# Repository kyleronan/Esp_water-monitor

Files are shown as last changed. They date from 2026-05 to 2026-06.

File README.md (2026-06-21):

# Water Monitor

A DIY Home Assistant addon and ESP32-based smart water shut-off valve.
Tracks pressure and flow, learns your home's normal usage, runs scheduled leak
tests, and lets you cut off water to the house from anywhere — without
subscriptions, cloud polling, or trips to the crawl space.

## Background

This started as a hobby project. I wasn't happy with the commercial options
(Moen Flo, StreamLabs Control) — they polled the internet for things that
should work locally, and put basic features behind subscriptions. I also got
tired of crawling under the house every winter to shut off water to the
irrigation, and wanted something I could trigger from an app or a wall switch.

So I built one. It's not as pretty or compact as the off-the-shelf products,
but it has most of the same basic features and runs entirely on my own LAN.

A few design choices worth knowing about up front:

- **Manual override matters.** From day one this had to work with physical
  switches and indicator lights, not just the web UI. If the network is down,
  if I'm not home, if Home Assistant is misbehaving — anyone in the house
  can still open or close the valve.
- **Two circuits.** Main (whole house) plus irrigation. The irrigation valve
  is the one I shut off for winter; having it on a separate circuit makes
  the seasonal routine a one-tap operation.
- **Overbuilt by choice.** Three-piece stainless steel ball valves (serviceable,
  lead-free, more trustworthy than the brass valves on AliExpress), motorised
  actuators with a manual override for power outages, separate pressure
  transducers and flow meters per circuit. You could absolutely build this
  with cheaper parts — most of the firmware doesn't care.
- **Cost-conscious sourcing.** Most components came from AliExpress because the
  same parts from local plumbing/HVAC suppliers were 10× the price. Links to
  what I actually used will go in `docs/` once the hardware build guide is
  written.
- **PCB caveat.** This was my first SMD design. The current revision works,
  but I have a small pile of boards on my shelf that don't. The board is
  optimised for *my* situation, not for manufacturing efficiency or BOM cost.

## On the code

I should be upfront about how this got built. I'm an amateur C coder at best,
and my prior web experience tops out at script-kiddie HTML and Java tinkering.
The firmware was within reach — I had a basically functional firmware and the
valve sitting in the basement "ready" for testing since August 2025 — but the
prospect of writing the Home Assistant addon, with its FastAPI backend, async
WebSockets, Jinja2 templates, SQLite migrations, and clustering algorithms, kept
stalling out against my ADHD. It sat on the shelf for a long time.

So I leaned on AI heavily and did a fair amount of vibe coding to get the
addon to a state where it's actually usable. Originally I figured this whole
project was just for me, but along the way I realised I should at least flesh
it out enough that someone else could build on the idea if they wanted to.
That's why the addon code is more polished than I'd ever have produced on my
own — and also why it might have rough edges only an experienced developer
would have caught.

If you find bugs or design choices that look weird, that's probably why. PRs
welcome.

## TL;DR

I made a thing. It mostly works. If you want to copy it or improve on it,
that's great. I'm probably not going to build another one for myself.

## What it does

- **Real-time monitoring** — pressure and flow on the main and irrigation
  circuits, displayed in the units you choose (L/min · gal/min · ft³/min ·
  m³/min, and PSI · bar · kPa)
- **Learned baseline** — 14-day calibration period during which the addon
  watches your normal usage patterns. When training ends, the Fixtures
  page lists the clusters that were detected; you confirm or remove them,
  then activate the circuit to start anomaly detection (or auto-activates
  after 7 days of no review).
- **Scheduled micro leak tests** — closes each valve in turn at the
  statistically quietest hour of the day, monitors pressure decay, and notifies
  on failure
- **Fixture identification** — clusters water events by their pressure and
  flow signatures to identify individual fixtures (toilets, showers, taps,
  appliances). Live in v0.2.0; naming UI complete; merge-clusters UI and
  ESP-side waveform enrichment added in v0.2.1.
- **Event detail modal** — every event in the History list opens an
  inspector with trigger type, peak flow, propagation delay, anomaly score
  and (with firmware v3.7+) an embedded waveform chart. Events can be
  re-assigned to a fixture or ignored from this view.
- **Degraded-supply guard** (v0.2.2) — detects when the municipal supply
  is pulsing (paddlewheel flow sensors produce garbage under those
  conditions). Affected events are flagged, given an envelope-smoothed
  volume so daily totals stay sensible, and excluded from clustering. The
  Dashboard shows a banner and the History page has a filter.
- **Per-circuit valve type** (v0.2.2) — Setup and Settings let you mark
  each circuit as 2-port (standard) or 3-port (drain-capable for
  winterization). 3-port circuits automatically skip the micro leak test
  (the drain port reads as a constant leak); the schedule is preserved
  if you ever switch back.
- **Runtime flow-meter calibration** (v0.2.2) — pulses-per-litre is a
  per-circuit Home Assistant number entity (NVS-backed, survives OTA), so
  any flow meter works without a firmware edit. A guided **calibration
  helper** (Settings → Flow Meter → Calibrate) measures the true
  pulses-per-litre from a bucket test or a whole-house municipal-meter
  reading — showing each run, their average and range, with an editable,
  safety-gated value before you apply.
- **Anomaly detection** (v0.2.2, Phase 2.3) — flags events that deviate from
  the learned baseline (volume percentiles + per-fixture envelopes) and can
  notify or auto-shut-off, guarded so a thin/young baseline degrades to
  notify-only.
- **Away mode** — pauses learning while unoccupied, automatically toggled
  from your existing HA presence entities
- **Mobile push notifications** for all alerts via HA's `notify.mobile_app_*`
  services, with per-target backoff after repeated failures so a broken
  mobile_app integration doesn't spam the logs.
- **Full backup and restore** — three-tier backup (Quick Restore JSON, History
  Archive SQLite, Full ZIP) with restore-from-backup in the setup wizard
- **Auto dark mode** — the UI follows your OS / browser appearance
  preference automatically. No toggle, no setup.

## Repository structure

This is a Home Assistant addon repository. It also contains the firmware,
documentation, and (eventually) a companion native HA integration.

```
.
├── repository.yaml      # HA addon repository metadata
├── water_monitor/       # The addon itself (HA expects this at the root)
│   ├── config.yaml
│   ├── Dockerfile
│   ├── icon.png         # Addon icon (128 × 128) — shown on HA addon card
│   ├── logo.png         # Addon logo (250 × 100) — shown on HA store detail page
│   └── app/
├── firmware/            # ESPHome firmware for the ESP32-S3-WROOM-1
├── integration/         # Native HA integration (planned for v0.4)
└── docs/                # Hardware build notes, pinouts, parts list
```

## Installation

### Addon

1. In Home Assistant: **Settings → Add-ons → Add-on Store**
2. Open the three-dot menu (top right) → **Repositories**
3. Paste this repository's URL:
   ```
   https://github.com/kyleronan/Esp_water-monitor
   ```
4. Click **Add**, then close the dialog
5. The **Water Monitor** addon will appear in the store — click it and **Install**
6. Open the addon's web UI and follow the setup wizard

Updates are delivered automatically — when a new version is pushed to this
repository, the HA addon store will offer the update.

### Hardware

You'll need the ESP32-S3-WROOM-1 board (custom PCB), motorised ball valves
with end-stop signalling, pressure transducers, and pulse-output flow meters.

> **If your home has a pressure boosting pump or well pump system**, install
> the addon's flow and pressure sensors *downstream* of the pump (between the
> pump output and the house plumbing). Sensors placed upstream see pump cycling
> artifacts that mask individual fixture pressure signatures, making the
> fixture identification feature in v0.2.x unreliable. Downstream placement is
> also what every reasonable installation diagram recommends regardless of
> monitoring.

PCB design files (KiCad + Gerbers), bill of materials, build guide, and bring-up checklist are in [`docs/hardware/`](docs/hardware/).

### Firmware

1. Copy `firmware/secrets.yaml.example` to `firmware/secrets.yaml` and fill
   in the five values (API encryption key, OTA password, fallback-AP
   password, web UI username + password). See
   [`firmware/README.md`](firmware/README.md) for the key-generation
   snippet and the security model.
2. Flash `firmware/esp-water-shut-off-3_12.yaml` (v3.12.0) to your
   ESP32-S3-WROOM-1 using ESPHome.
3. Make sure the device is added to Home Assistant before installing the
   addon.
4. The setup wizard will discover the device automatically.

Before tagging a firmware release, run
`python scripts/check_firmware_release.py` — it parses the YAML and
fails if any credential is missing or if `dashboard_import` still
points at a mutable branch ref.

## Project status

| Phase | Scope | Status |
|---|---|---|
| **0.1.x** | Core monitoring, leak detection, calibration, display units | Shipped |
| **0.2.0** | Fixture identification — clustering engine live, naming UI complete | Shipped |
| **0.2.1** | ESP-side waveform capture & feature enrichment, event detail modal, merge-clusters UI, Basic/Advanced settings split, auto dark mode, hardware docs (PCB v1.2a) | Shipped |
| **0.2.2** | Runtime per-circuit flow-meter PPL + guided flow-calibration helper (bucket / municipal), Phase 2.3 anomaly detection, degraded-supply guard, per-circuit valve type (2-port / 3-port), per-session CSRF refactor, autocorrelation correctness fix, firmware release-gate script, migration transaction safety, async/blocking SQLite audit, live-capture reliability fixes (importer catch-up checkpoint + stuck no-flow phantom close) | Shipped |
| **0.3.x** | Per-circuit pressure-sensor calibration, esp_idf framework migration with proper task watchdog | Planned |
| **0.4.x** | Native Home Assistant integration (alongside the addon, eventually replacing the WebSocket bridge for users who prefer pip-installable components) | Planned |

See `CHANGELOG.md` for detailed release notes, and
[`docs/TODO.md`](docs/TODO.md) for the running list of manual follow-ups
(real-sample capture for the degraded-supply detector, per-circuit
pressure calibration, etc).

## License

MIT — see `LICENSE` file. Use it, modify it, sell it, build a better one,
whatever you like. Attribution is appreciated but not required.

## Contributing

This repository is in active development; the API and database schema may
change between minor versions. If you build one and find bugs or have ideas,
issues and PRs are welcome — though responses may be slow given this is a
side project.

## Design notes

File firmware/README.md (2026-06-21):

# Firmware — ESP Water Monitor

ESPHome firmware for the ESP32 water shut-off controller. 

## First-time setup

Before compiling you must create a `secrets.yaml` file in this directory:

```bash
cp firmware/secrets.yaml.example firmware/secrets.yaml
```

Then edit `firmware/secrets.yaml` and fill in all values. ESPHome will refuse to
compile if any `!secret` key is missing.

**Do not commit `secrets.yaml`** — it is listed in `.gitignore`.

### Generating an API encryption key

The `api_encryption_key` must be a base64-encoded 32-byte random value:

```bash
python3 -c "import base64, os; print(base64.b64encode(os.urandom(32)).decode())"
```

Paste the output into `secrets.yaml` as the value for `api_encryption_key`.

## Security notes

| Feature | Config |
|---|---|
| ESPHome API | Encrypted — key in `secrets.yaml` |
| OTA updates | Password-protected — set in `secrets.yaml` |
| Fallback hotspot | Password-protected — set in `secrets.yaml` |
| Built-in web UI | Basic auth — credentials in `secrets.yaml` |
| Bluetooth provisioning | `authorizer: none` — any nearby device can provision via Improv. Disable `esp32_improv` in the YAML if this is a concern. |

## Per-circuit pressure calibration

Both pressure transducers default to a shared factory-typical linear
fit. After bench measurement, override the per-circuit calibration via
the `substitutions:` block at the top of
`esp-water-shut-off-3_10.yaml` — eight values
(`pressure_cal_main_zero_raw / _psi`, `pressure_cal_main_max_raw /
_psi`, plus the irrigation counterparts). See
[`docs/hardware/bring-up-checklist.md`](../docs/hardware/bring-up-checklist.md)
for the two-point measurement procedure.

The defaults work for un-calibrated installs (existing flashes keep
their behaviour unchanged), but per-circuit calibration removes
transducer-to-transducer bias and makes the micro leak test more
sensitive.

## Releasing

Before tagging a firmware release, run the release-check script:

```bash
python scripts/check_firmware_release.py
```

It fails (non-zero exit) when any of these are missing or wrong in
`firmware/esp-water-shut-off-3_10.yaml`:

- `api.encryption.key`
- `ota[*].password`
- `wifi.ap.password`
- `web_server.auth.username` / `web_server.auth.password`
- `dashboard_import.package_import_url` not pinned to an immutable tag
  (`@v3.10.0`, etc.) or commit SHA — `@main` is rejected

When bumping the firmware version, update `dashboard_import.package_import_url`
to the new tag at the same time as the version field. The check script
parses the YAML, so commented-out example lines don't fool it.

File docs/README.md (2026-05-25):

# Hardware Documentation

See [docs/hardware/README.md](hardware/README.md) for the hardware build guide,
bill of materials, and bring-up checklist.

See [firmware/esp-water-shut-off-3_10.yaml](../firmware/esp-water-shut-off-3_10.yaml)
for the current ESPHome configuration.

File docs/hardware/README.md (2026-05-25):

# Hardware Documentation

This folder documents the ESP32 Water Valve Controller hardware build.

Use the board labels from the PCB and KiCad files throughout the hardware docs:

- Valve 1
- Valve 2

Software may allow custom names later, but the hardware build guide uses the physical board labels.

## Main documents

- `bom.md` - simplified builder-facing BOM
- `pinouts.md` - board connector pinouts
- `breakaway-front-panel-controls.md` - optional manual/auto front-panel control board
- `bring-up-checklist.md` - first power-up and test checklist

## Hardware Build Guide

This is a high-level build guide for the ESP32 Water Valve Controller hardware.

### Build order

1. Inspect the bare PCB.
2. Assemble the PCB.
3. Inspect solder joints and orientation-sensitive parts.
4. Separate the breakaway front-panel control section if it will be used.
5. Mount the main PCB in the enclosure.
6. Mount the breakaway control section and panel LEDs on the enclosure front panel.
7. Wire the 12 V DIN rail power supply and DIN terminal blocks.
8. Wire Valve 1 and Valve 2.
9. Wire the flow and pressure sensors.
10. Power up without plumbing pressure and run the bring-up checklist.
11. Test valve open/close behavior.
12. Test sensor readings.
13. Perform plumbing tests and calibration.

## Build photos

These photos document the prototype, assembly, enclosure wiring, plumbing test, pressure calibration, front panel, and breakaway switch wiring.

### Photo index

| Photo | Description |
| --- | --- |
| [Early prototyping](images/early-prototyping.jpg) | Early hardware prototyping before the final enclosure layout. |
| [Soldering complete](images/soldering-complete.jpg) | Assembled PCB after soldering. |
| [First enclosure wiring and testing](images/first-enclosure-wiring-and-testing.jpg) | Initial wiring inside the enclosure during testing. |
| [First plumbing test](images/first-plumbing-test-hose-floor-drain.jpg) | Initial plumbing test using a hose and floor drain. |
| [Pressure sensor calibration](images/pressure-sensor-calibration-analog-gauge.jpg) | Pressure sensor calibration using an analog pressure gauge. |
| [Inside of enclosure](images/inside-enclosure.jpg) | Internal enclosure layout with mounted electronics and wiring. |
| [Breakaway switch board wiring](images/breakaway-switch-board-bypass-wiring-enclosure-door.jpg) | Breakaway switch/control board bypass wiring mounted on the enclosure door. |
| [Outside of enclosure with LEDs](images/outside-enclosure-leds-wip.jpg) | Front of the enclosure showing panel LEDs. Work in progress; final labels still needed. |
| [ESP32-S3 WROOM-1 pinout](images/esp32s3_wroom1_pinout.png) | Pin reference diagram for the ESP32-S3 WROOM-1 module used in this build. |

### Gallery

#### Early prototyping

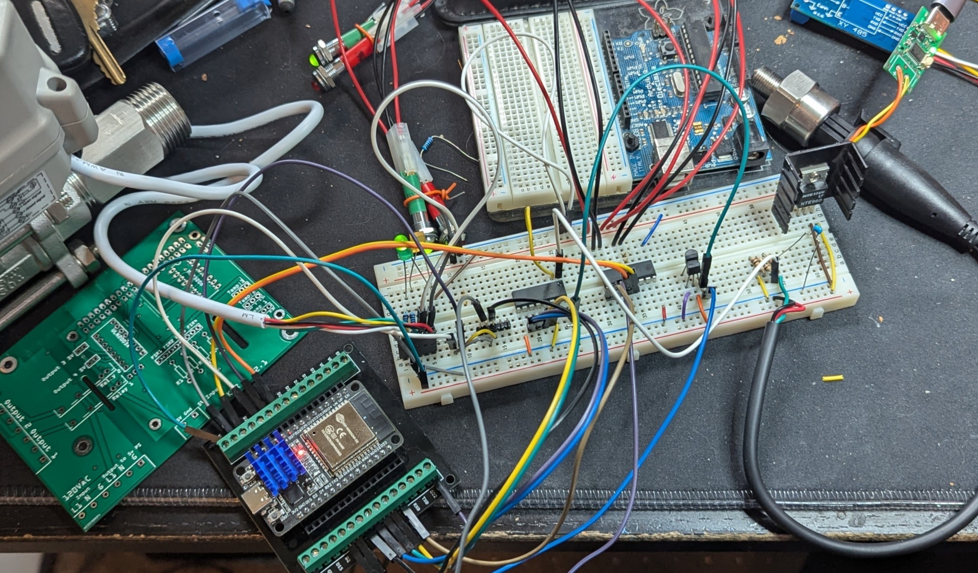
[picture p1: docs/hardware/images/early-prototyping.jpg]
Early prototyping


Early hardware prototyping before the final enclosure layout.

#### Soldering complete

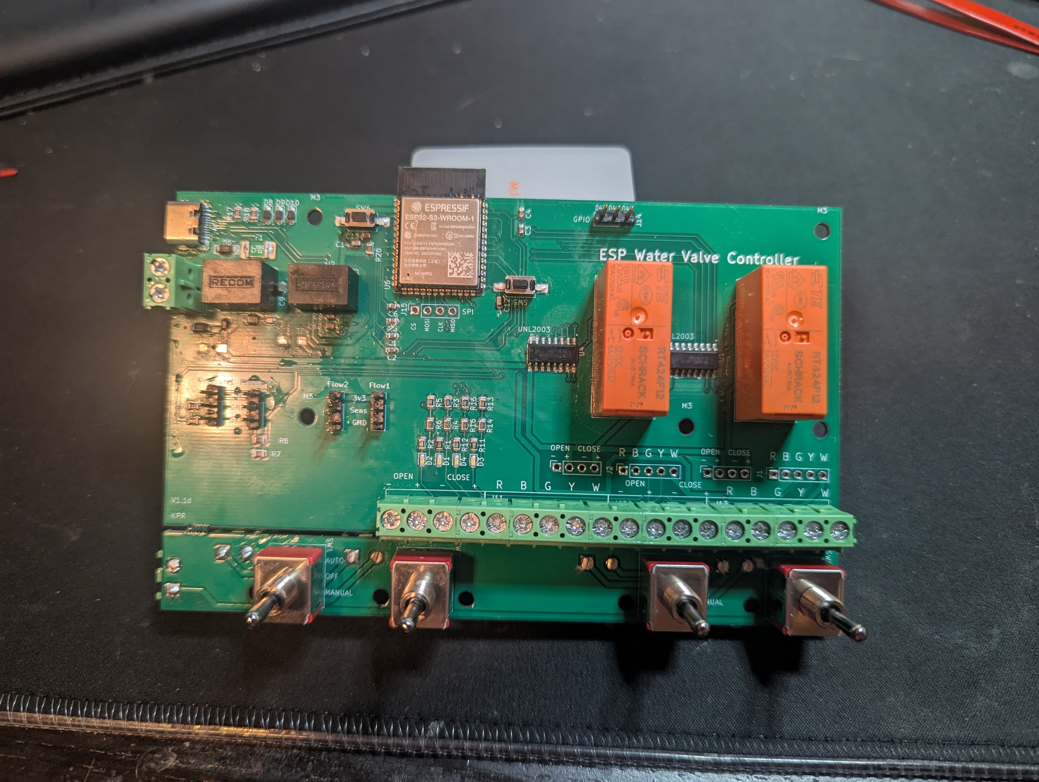
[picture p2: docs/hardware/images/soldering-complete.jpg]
Soldering complete


Assembled PCB after soldering.

#### First enclosure wiring and testing

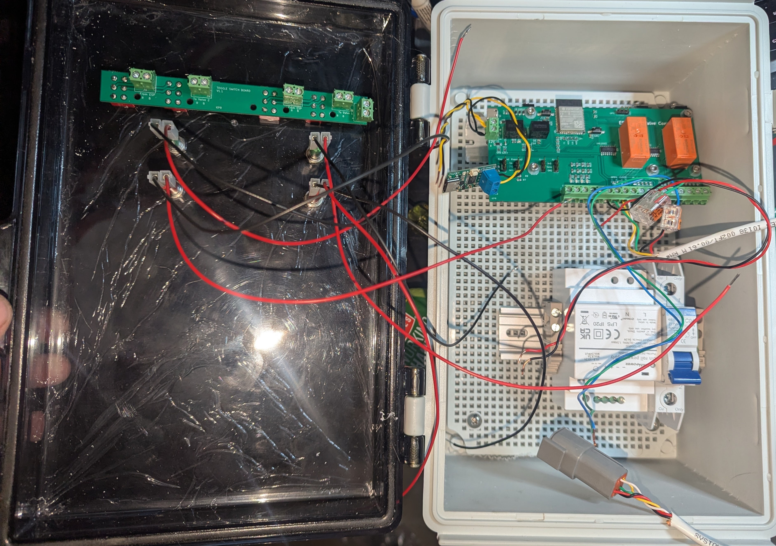
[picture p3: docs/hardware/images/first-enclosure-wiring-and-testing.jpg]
First enclosure wiring and testing


Initial wiring inside the enclosure during testing.

#### First plumbing test

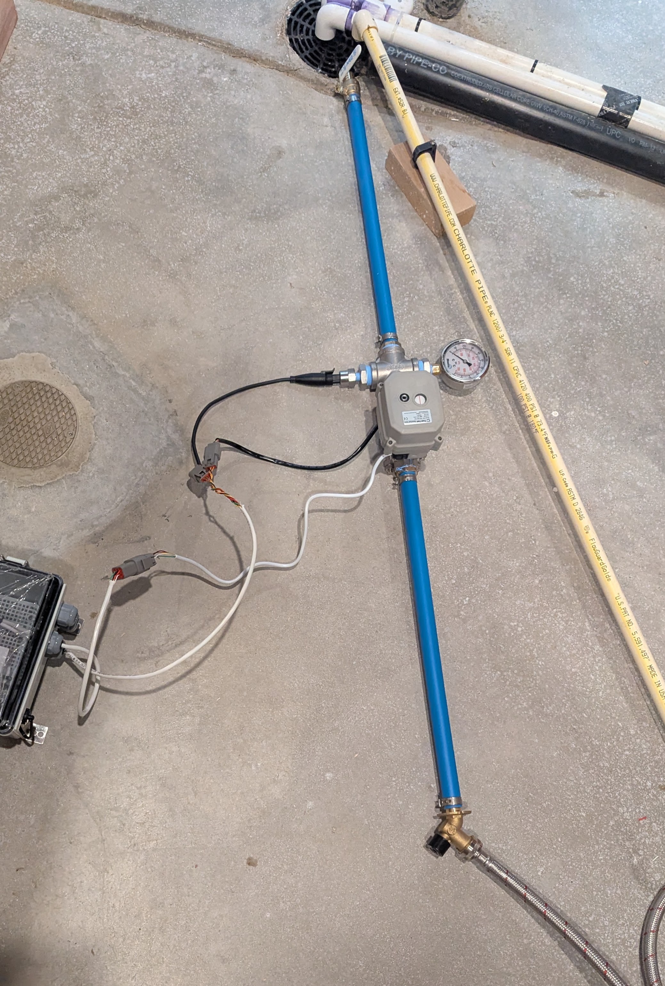
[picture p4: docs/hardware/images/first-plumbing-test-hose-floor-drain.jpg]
First plumbing test


Initial plumbing test using a hose and floor drain.
#### Pressure sensor calibration

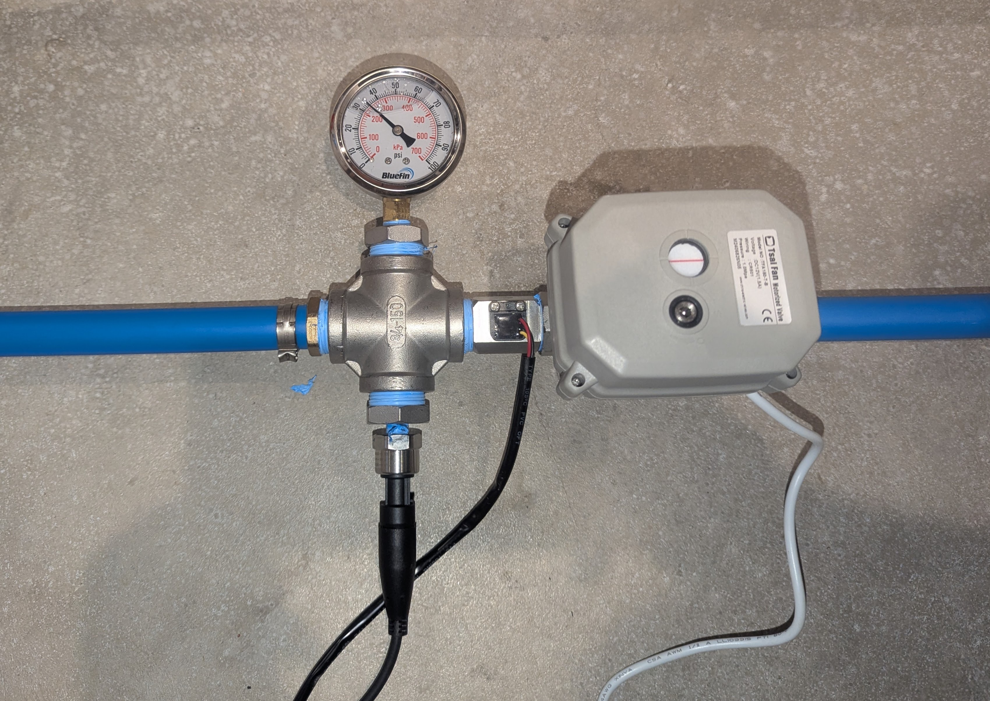
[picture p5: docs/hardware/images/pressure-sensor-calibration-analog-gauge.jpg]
Pressure sensor calibration


Pressure sensor calibration using an analog pressure gauge.

#### Inside of enclosure

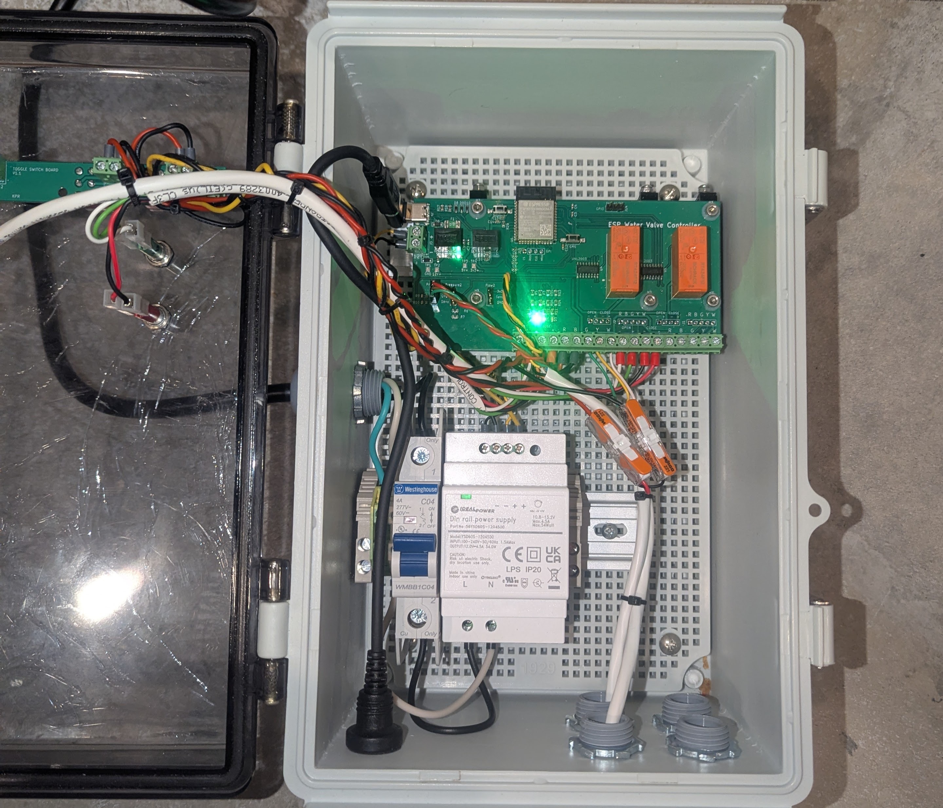
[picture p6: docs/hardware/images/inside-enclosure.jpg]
Inside of enclosure


Internal enclosure layout with mounted electronics and wiring.

#### Breakaway switch board wiring

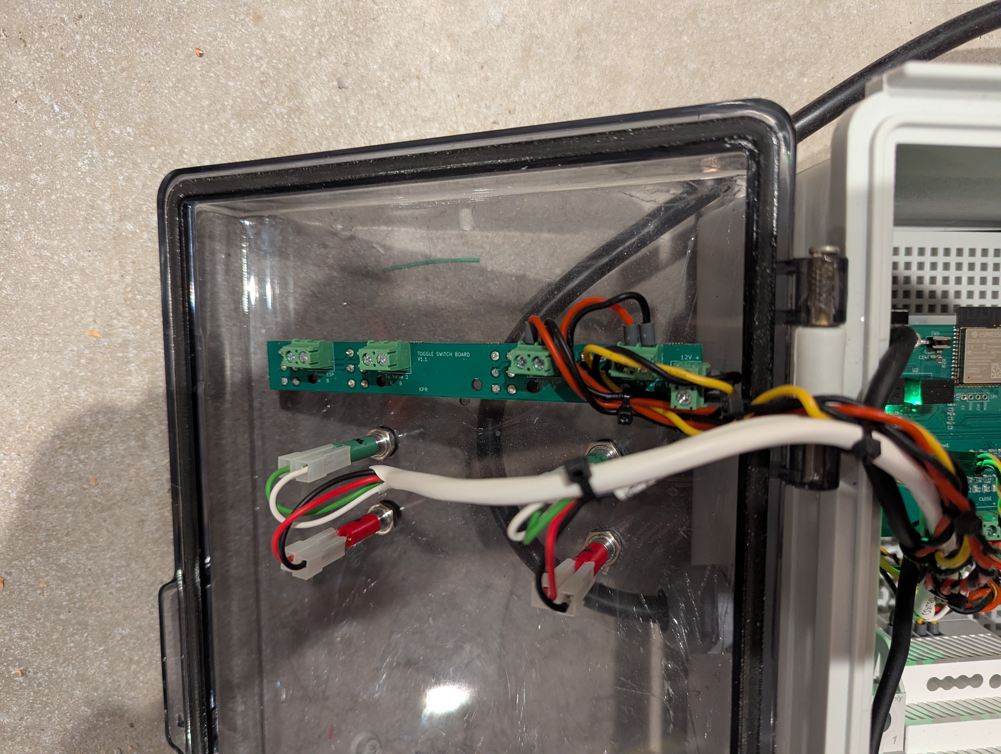
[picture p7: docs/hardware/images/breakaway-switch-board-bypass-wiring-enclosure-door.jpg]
Breakaway switch board wiring


Breakaway switch/control board bypass wiring mounted on the enclosure door.

#### Outside of enclosure with LEDs

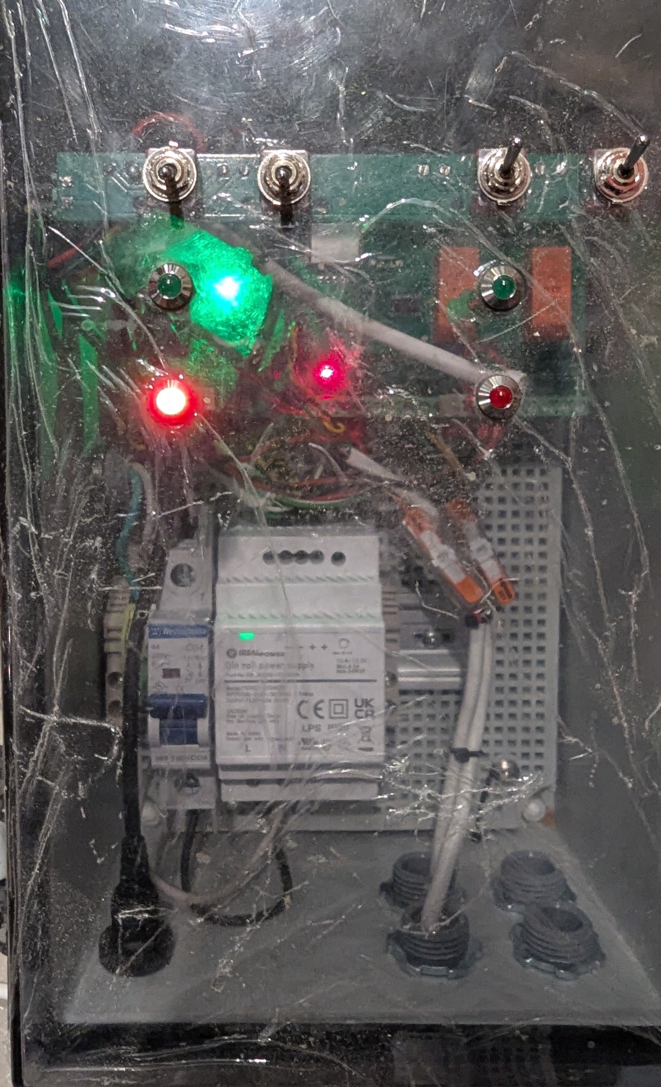
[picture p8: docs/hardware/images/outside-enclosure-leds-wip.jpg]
Outside of enclosure with LEDs


Front of the enclosure showing panel LEDs. Work in progress; final labels still needed.

#### ESP32-S3 WROOM-1 pinout

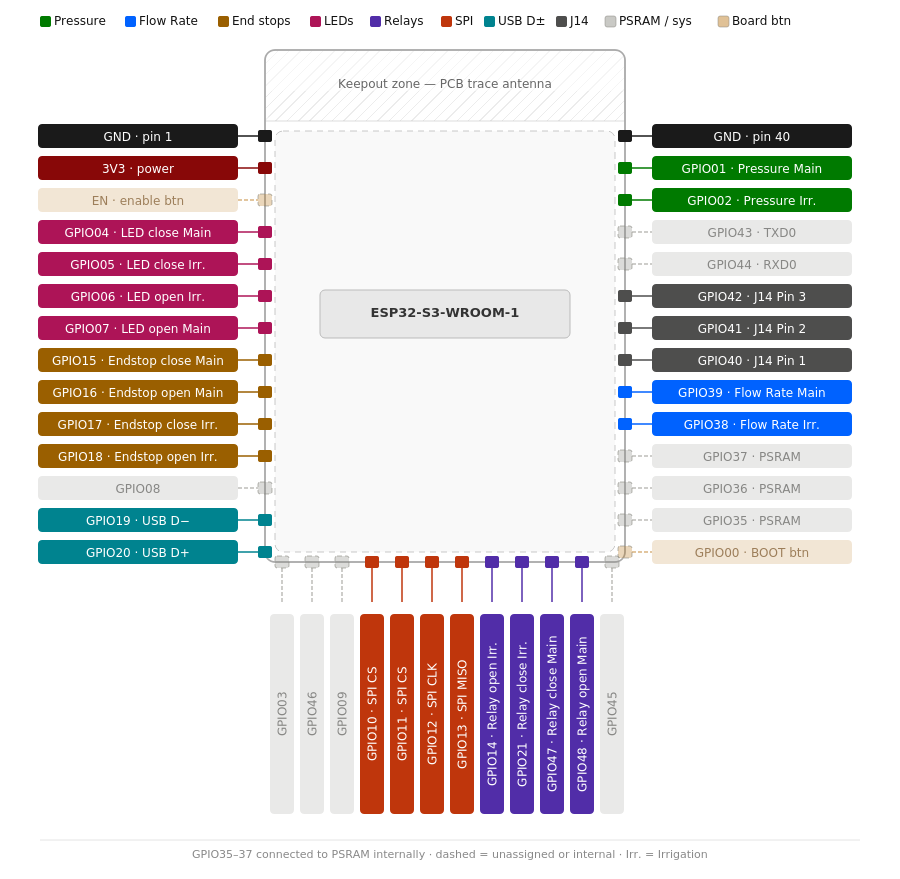
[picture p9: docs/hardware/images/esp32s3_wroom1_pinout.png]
ESP32-S3 WROOM-1 pinout


Pin reference diagram for the ESP32-S3 WROOM-1 module used in this build.

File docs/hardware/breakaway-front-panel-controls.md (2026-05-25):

# Breakaway Front-Panel Controls

The bottom section of the PCB is designed as a breakaway section for optional front-panel manual control.

The main PCB stays mounted inside the enclosure. The breakaway switch section can be mounted on the enclosure front panel near the panel LEDs.

## Switch behavior

### Manual / Auto switch

| Position | Behavior |
| --- | --- |
| Auto | Software control. The main PCB and ESP32 control the valve. |
| Manual | Front-panel open/close switch control. ESP32 software control is bypassed. |

### Open / Close switch

| Position | Behavior |
| --- | --- |
| Open | Motor is powered toward the open position. |
| Close | Motor is powered toward the closed position. |
| Center/off | Not applicable. This switch does not have a center/off position. |

## Wiring path

The breakaway switch board is inserted inline with the valve motor wires.

```text
Main PCB R/B motor output
  -> breakaway board "From ESP" R/B
  -> manual/auto switching section
  -> breakaway board "To Valve" R/B
  -> valve motor R/B
```

## Offline behavior

Manual mode can still control the valve if the ESP32 is offline, as long as the main board and enclosure still have power for the switches, motor, and LEDs.

The ESP32 does not read the optional switch state in this hardware bypass path.

## Terminal labels

| Breakaway terminal label | Purpose |
| --- | --- |
| `From ESP` | Receives the main PCB `R` and `B` motor output lines. |
| `To Valve` | Connects to the valve motor `R` and `B` wires. |

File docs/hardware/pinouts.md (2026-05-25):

# Pinouts

This page summarizes the important board connector pinouts.

## Valve connectors

| Connector | Channel | Use |
| --- | --- | --- |
| `J11` | Valve 1 | CR501 valve motor and feedback wires |
| `J13` | Valve 2 | CR501 valve motor and feedback wires |

| PCB label | Valve wire | Function |
| --- | --- | --- |
| `R` | Red | Motor lead |
| `B` | Black | Motor lead |
| `G` | Green | Fully-open feedback |
| `Y` | Yellow | Fully-closed feedback |
| `W` | White | Feedback common |

### Valve Wiring

The build uses CR5 01 / CR501 12 V DC motorized ball valves.

### Motor control

| Command | Black wire / `B` | Red wire / `R` | Result |
| --- | --- | --- | --- |
| Open | +12 V DC | GND / - | Valve opens |
| Close | GND / - | +12 V DC | Valve closes |
| Idle | Unpowered | Unpowered | Motor off |

The manufacturer note says the internal limit switch cuts motor power automatically when the valve reaches fully open or fully closed.

### Feedback contacts

| Valve position | Contact closure |
| --- | --- |
| Fully open | White / `W` to Green / `G` |
| Fully closed | White / `W` to Yellow / `Y` |

The feedback wires are connected to the PCB.

### Optional breakaway control board

If the breakaway front-panel control board is installed, the valve motor `R` and `B` lines pass through it:

```text
Main PCB R/B
  -> breakaway board "From ESP" R/B
  -> manual/auto switch path
  -> breakaway board "To Valve" R/B
  -> valve motor R/B
```

In Auto mode, main PCB software control passes through. In Manual mode, the front-panel open/close switch bypasses ESP32 software control and drives the motor from the 12 V source.

## Panel LED connectors

| Connector | Channel | Use |
| --- | --- | --- |
| `J10` | Valve 1 | External panel LEDs |
| `J12` | Valve 2 | External panel LEDs |

For both `J10` and `J12`:

| LED | Terminals | Meaning |
| --- | --- | --- |
| Green panel LED | `Open +` / `Open -` | Valve open indicator |
| Red panel LED | `Close +` / `Close -` | Valve closed indicator |

## Flow sensor connectors

| Connector | Pin 1 | Pin 2 | Pin 3 |
| --- | --- | --- | --- |
| `Flow1` | Red / + supply / `/3v3` | Yellow / pulse / `GPIO39` | Black / GND / `Earth` |
| `Flow2` | Red / + supply / `/3v3` | Yellow / pulse / `GPIO38` | Black / GND / `Earth` |

Because the flow sensor is powered from 3.3 V, the yellow pulse output can connect directly to the ESP32 GPIO input without a voltage divider or other signal conditioning.

## Pressure sensor connectors

| Connector | Pin 1 | Pin 2 | Pin 3 |
| --- | --- | --- | --- |
| `Pressure1` | Red / + supply / `/5V` | Black / GND / `Earth` | Green / sense, through divider to `GPIO1` |
| `Pressure2` | Red / + supply / `/5V` | Black / GND / `Earth` | Green / sense, through divider to `GPIO2` |

The pressure sensor output is 0.5 to 4.5 V. The PCB resistor divider scales the signal for ESP32 ADC input.

## Pressure sense scaling

| Sensor | Sense pin | Series resistor | ESP32 ADC net | Pulldown resistor |
| --- | --- | --- | --- | --- |
| Pressure 1 | `Pressure1` pin 3 | `R10` 10K | `GPIO1` | `R9` 20K to ground |
| Pressure 2 | `Pressure2` pin 3 | `R8` 10K | `GPIO2` | `R7` 20K to ground |

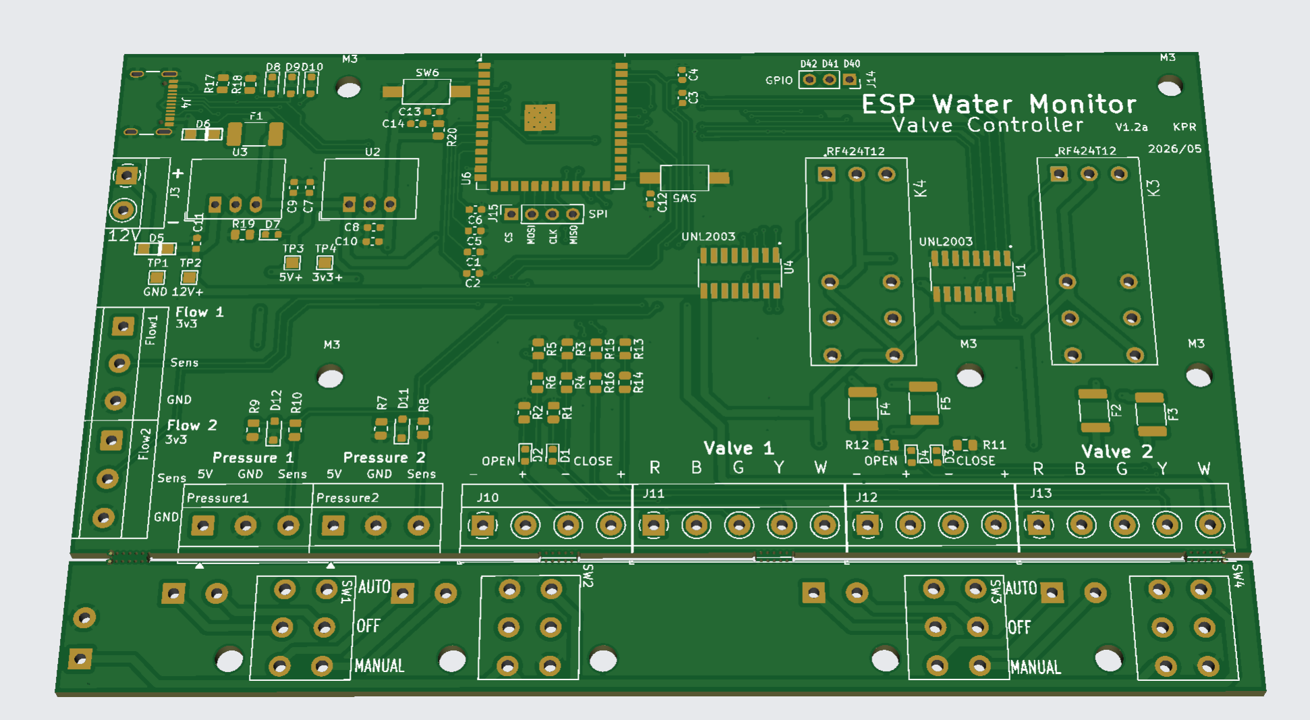
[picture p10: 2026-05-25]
docs/hardware/images/PCB-image-1.2a.png

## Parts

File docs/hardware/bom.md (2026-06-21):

# Bill of Materials

This is the simplified builder-facing BOM for the PCB and related hardware.

## Important BOM notes

- The KiCad source files included in this package use `470R` for the installed resistor value.
- For 4-position terminal groups, the build uses two Phoenix Contact `1935161` 2-position terminal blocks.
- The confirmed quantity for Phoenix Contact `1935161` terminal blocks is 9 per build.
- Majority of PCB components were purchased from Digikey

## PCB BOM

| Qty | References | Value | Footprint | Part | Supplier Part # | Notes |
| --- | --- | --- | --- | --- | --- | --- |
| 6 | C1, C2, C3, C4, C5, C6 | `0.01uF` | `Capacitor_SMD:C_0603_1608Metric` | KEMET C0603C103J3HACTU | `399-C0603C103J3HACTUCT-ND` |  |
| 5 | C9, C10, C12, C13, C14 | `0.1uF` | `Capacitor_SMD:C_0603_1608Metric` | TDK C1608X8R1E104K080AA | `445-2500-1-ND` |  |
| 3 | C7, C8, C11 | `10uF` | `Capacitor_SMD:C_0603_1608Metric` | Samsung Electro-Mechanics CL10X106MO8NRNC | `1276-6769-1-ND` |  |
| 2 | Led1, Led2 | `Conn_01x04_Socket` | `Connector_PinSocket_2.54mm:PinSocket_1x04_P2.54mm_Vertical` | Phoenix Contact 1935161 | `277-1667-ND` | Uses two 2-position 1935161 terminal blocks per 4-position connector group |
| 2 | J1, J2 | `Conn_01x05_Pin` | `Connector_PinSocket_2.54mm:PinSocket_1x05_P2.54mm_Vertical` | Phoenix Contact 1935161 | `277-1667-ND` | Uses PCB terminal blocks, confirmed total 1935161 quantity is 9 per build |
| 2 | J7, J9 | `From PCB` | `TerminalBlock_Phoenix:TerminalBlock_Phoenix_MKDS-1,5-2_1x02_P5.00mm_Horizontal` | Phoenix Contact 1935161 | `277-1667-ND` |  |
| 1 | J14 | `GPIO` | `Connector_PinSocket_2.54mm:PinSocket_1x03_P2.54mm_Vertical` |  |  |  |
| 1 | J15 | `SPI` | `Connector_PinSocket_2.54mm:PinSocket_1x04_P2.54mm_Vertical` | Phoenix Contact 1935161 | `277-1667-ND` | Uses two 2-position 1935161 terminal blocks per 4-position connector group |
| 2 | J3, J8 | `Screw_Terminal_01x02` | `TerminalBlock_Phoenix:TerminalBlock_Phoenix_MKDS-1,5-2_1x02_P5.00mm_Horizontal` | Phoenix Contact 1935161 | `277-1667-ND` |  |
| 2 | J10, J12 | `Screw_Terminal_01x04` | `TerminalBlock_Phoenix:TerminalBlock_Phoenix_MKDS-1,5-4_1x04_P5.00mm_Horizontal` | Phoenix Contact 1935161 | `277-1667-ND` | Uses two 2-position 1935161 terminal blocks per 4-position connector group |
| 2 | J11, J13 | `Screw_Terminal_01x05` | `TerminalBlock_Phoenix:TerminalBlock_Phoenix_MKDS-1,5-5_1x05_P5.00mm_Horizontal` | Phoenix Contact 1935161 | `277-1667-ND` | Uses PCB terminal blocks, confirmed total 1935161 quantity is 9 per build |
| 2 | J5, J6 | `To Motor` | `TerminalBlock_Phoenix:TerminalBlock_Phoenix_MKDS-1,5-2_1x02_P5.00mm_Horizontal` | Phoenix Contact 1935161 | `277-1667-ND` |  |
| 1 | J4 | `USB_C_Receptacle_USB2.0_16P` | `Connector_USB:USB_C_Receptacle_GCT_USB4105-xx-A_16P_TopMnt_Horizontal` | GCT USB4215-03-A | `2073-USB4215-03-ACT-ND` | Verify footprint vs purchased connector |
| 2 | D5, D6 | `MBR140SFT3G` | `mbr140sft3g:SOD-123FLv2` | onsemi MBR140SFT3G | `MBR140SFT3GOSCT-ND` |  |
| 1 | U6 | `ESP32-S3-WROOM-1` | `RF_Module:ESP32-S3-WROOM-1` | Espressif ESP32-S3-WROOM-1-N8R2 | `1965-ESP32-S3-WROOM-1-N8R2-ND` |  |
| 1 | U2 | `R-783.3-1.0` | `Converter_DCDC:Converter_DCDC_RECOM_R-78E-0.5_THT` | Recom Power R-783.3-1.0 | `945-1036-ND` |  |
| 1 | U3 | `R-78E5.0-1.0` | `Converter_DCDC:Converter_DCDC_RECOM_R-78E-0.5_THT` | Recom Power R-78E5.0-1.0 | `945-2201-ND` |  |
| 2 | U1, U4 | `ULN2003ADR` | `ULN2003ADR:SOIC127P600X175-16N` | Texas Instruments ULN2003ADR | `296-1368-1-ND` |  |
| 3 | D1, D3, D7 | `LED_Green` | `LED_SMD:LED_0603_1608Metric` | Harvatek B1931NG--20D001114U1930 | `3147-B1931NG--20D001114U1930CT-ND` |  |
| 2 | D2, D4 | `LED_Red` | `LED_SMD:LED_0603_1608Metric` | Harvatek B1931URO-20D000114U1930 | `3147-B1931URO-20D000114U1930CT-ND` |  |
| 1 | F1 | `1.5A` | `Fuse:Fuse_1812_4532Metric_Pad1.30x3.40mm_HandSolder` | Bel Fuse 0ZCG0150AF2C | `5923-0ZCG0150AF2CCT-ND` |  |
| 4 | Flow1, Flow2, Pressure1, Pressure2 | `Conn_01x03_Pin` | `Connector_PinSocket_2.54mm:PinSocket_1x03_P2.54mm_Vertical` |  |  |  |
| 3 | D8, D9, D10 | `D_TVS` | `Diode_SMD:D_SOD-323_HandSoldering` | Diodes Inc. D5V0F1B2WS-7 | `31-D5V0F1B2WS-7CT-ND` | Verify footprint/package |
| 2 | K3, K4 | `RT424F12` | `RT42f12:TE_5-1393243-4` | TE Connectivity Potter & Brumfield RT424F12 | `RT424F12-ND` |  |
| 7 | R4, R6, R8, R10, R14, R16, R20 | `10K` | `Resistor_SMD:R_0805_2012Metric` | Stackpole RMCF0805FT10K0 | `RMCF0805FT10K0CT-ND` |  |
| 6 | R3, R5, R7, R9, R13, R15 | `20K` | `Resistor_SMD:R_0805_2012Metric` | Stackpole RMCF0805FT20K0 | `RMCF0805FT20K0CT-ND` |  |
| 5 | R1, R2, R11, R12, R19 | `470R` | `Resistor_SMD:R_0805_2012Metric` | Stackpole RMCF0805FT470R | `RMCF0805FT470RCT-ND` |  |
| 2 | R17, R18 | `5.1K` | `Resistor_SMD:R_0805_2012Metric` | Stackpole RMCF0805FT5K10 | `RMCF0805FT5K10CT-ND` |  |
| 1 | SW1 | `Control 1` | `Toggle_switch:ANT23SECQE DPDT` |  |  |  |
| 1 | SW3 | `Control 2` | `Toggle_switch:ANT23SECQE DPDT` |  |  |  |
| 1 | SW2 | `Open_Close_1` | `Toggle_switch:ANT23SECQE DPDT` |  |  |  |
| 1 | SW4 | `Open_Close_2` | `Toggle_switch:ANT23SECQE DPDT` |  |  |  |
| 2 | SW5, SW6 | `SW_Push` | `Push_button_Switch:SW PTS636 SP50 SMTR LFS` | C&K PTS636 SP50 SMTR LFS | `CKN12316-1-ND` |  |
| 1 | TP2 | `12V+` | `TestPoint:TestPoint_Pad_1.5x1.5mm` |  |  |  |
| 1 | TP4 | `3v3+` | `TestPoint:TestPoint_Pad_1.5x1.5mm` |  |  |  |
| 1 | TP3 | `5V+` | `TestPoint:TestPoint_Pad_1.5x1.5mm` |  |  |  |
| 1 | TP1 | `GND` | `TestPoint:TestPoint_Pad_1.5x1.5mm` |  |  |  |

## Enclosure and field hardware

### Pressure sensor

- Supplier: Amazon
- ASIN: `B0CFJ7BN3L` https://www.amazon.com/dp/B0CFJ7BN3L
- Type: 100 PSI pressure transducer
- Thread: 1/8"-27 NPT
- Supply: 5 to 16 V DC
- Output: 0.5 to 4.5 V analog
- Material: 316 stainless steel
- Listed waterproof rating: IP65

#### Pressure sensor wiring

| Wire color | Function |
| --- | --- |
| Red | Supply + |
| Black | Ground |
| Green | Analog sense output |

Pressure sensors are powered from 5 V. The sense output is scaled by a resistor divider before reaching the ESP32 ADC input.

### Flow sensor

- Supplier: AliExpress
- Item: `3256804293371927` https://www.aliexpress.us/item/3256804293371927.html
- Selected version: 5 V version
- Used from the PCB 3.3 V supply because the sensor works down to 3.3 V

#### Pulses per litre (PPL) — set per circuit

The firmware no longer hard-codes a flow K-factor. Each circuit exposes a
`Flow Meter PPL - <circuit>` number entity (NVS-backed). Conversion:
`L/min = pulses_per_minute ÷ PPL`.

Set it to match the meter you installed in **either** of two ways:
- **At flash time (recommended for a new build):** set the `flow_ppl_main` / `flow_ppl_irr`
  substitutions at the top of the firmware before flashing. This seeds the entity's
  initial value, so the unit is correctly calibrated from first boot with no HA.
- **At runtime:** set the number entity in Home Assistant or on the device's own web page.

`restore_value` keeps the value across reboots **and OTA firmware updates** — it is never
lost on an update. A meter rarely changes; to change it later, set the runtime entity, or
clean-flash to re-apply a new substitution (a plain OTA reflash keeps the saved value).

| Meter | Type | PPL | Notes |
| --- | --- | --- | --- |
| YF-B5 (default) | turbine, hall-effect | 396 | `F = 6.6 Hz per L/min × 60` |
| ZJ-HSM-OFZATS-06 | oval-gear positive displacement, hall-effect | 72 | `F = 1.2 × Q`; ±1%; 30–3000 L/h (0.5–50 L/min); ~5–6× cost; more accurate at low flow but debris/over-speed sensitive |

For an unlisted meter, use its datasheet PPL, or **bucket-test**: run a known volume through
and divide the counted pulses by the measured litres. Changing PPL triggers a per-circuit
re-baseline (auto-shutoff pauses until it matures); past usage totals are not recalculated.

#### Flow sensor wiring

| Wire color | Function |
| --- | --- |
| Red | Supply + |
| Black | Ground |
| Yellow | Pulse output |

The flow sensor pulse output connects directly to the ESP32 GPIO input. No voltage divider or extra signal conditioning is needed because the sensor is powered from 3.3 V.

### Valve

- Ball valve item: AliExpress `3256803975349392` https://www.aliexpress.us/item/3256803975349392.html
- Valve motor item: AliExpress `3256804718502721` https://www.aliexpress.us/item/3256804718502721.html
- Size: 3/4 inch
- Control type: CR5 01 / CR501
- Voltage: 12 V DC
- Thread type: NPT
- Material: 304 stainless steel
- Pressure rating: 600 WOG

Verify local plumbing requirements and potable-water suitability before installation.

### Enclosure

- Supplier: Amazon
- ASIN: `B0CSJXTLGZ` https://www.amazon.com/dp/B0CSJXTLGZ
- Style: lockable outdoor weatherproof enclosure
- Size selected: 11.4 in x 7.5 in x 5.5 in
- DIN terminal blocks: Dinkle DK2.5N, 12 to 22 AWG, various colors
- Cable glands: TE Connectivity ENTRELEC `1SNG601161R0000`
- 12 V DIN rail power supply: Ideal Power `56YSD60S-1204500`

### Panel accessories

| Qty | Part | Description |
| ---: | --- | --- |
| 2 | McMaster-Carr `2779K111` | Green 12 V DC quick-disconnect panel LED, 5/16 inch panel cutout |
| 2 | McMaster-Carr `2779K113` | Red 12 V DC quick-disconnect panel LED, 5/16 inch panel cutout |

Quick-disconnect terminals are used for the external panel LED wiring.

### DIN rail power supply

The build uses an Ideal Power `56YSD60S-1204500` 12 V DIN rail power supply.

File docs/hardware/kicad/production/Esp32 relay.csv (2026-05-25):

Id | Designator | Footprint | Quantity | Designation | Supplier and ref
1 | C1, C2, C3, C4, C5, C6 | C_0603_1608Metric | 6 | 0.01uF
2 | C7, C8, C11 | C_0603_1608Metric | 3 | 10uF
3 | C9, C10, C12, C13, C14 | C_0603_1608Metric | 5 | 0.1uF
4 | D1, D3, D7 | LED_0603_1608Metric | 3 | LED_Green
5 | D2, D4 | LED_0603_1608Metric | 2 | LED_Red
6 | D5, D6 | SOD-123FLv2 | 2 | MBR140SFT3G
7 | D8, D9, D10, D11, D12 | D_SOD-323_HandSoldering | 5 | D_TVS
8 | F1, F2, F3, F4, F5 | Fuse_1812_4532Metric_Pad1.30x3.40mm_HandSolder | 5 | 1.5A
9 | Flow1, Flow2, Pressure1, Pressure2 | TerminalBlock_Phoenix_MKDS-1,5-3_1x03_P5.00mm_Horizontal | 4 | Screw_Terminal_01x03
10 | J3, J8 | TerminalBlock_Phoenix_MKDS-1,5-2_1x02_P5.00mm_Horizontal | 2 | Screw_Terminal_01x02
11 | J4 | USB_C_Receptacle_GCT_USB4105-xx-A_16P_TopMnt_Horizontal | 1 | USB_C_Receptacle_USB2.0_16P
12 | J5, J6 | TerminalBlock_Phoenix_MKDS-1,5-2_1x02_P5.00mm_Horizontal | 2 | To Motor
13 | J7, J9 | TerminalBlock_Phoenix_MKDS-1,5-2_1x02_P5.00mm_Horizontal | 2 | From PCB
14 | J10, J12 | TerminalBlock_Phoenix_MKDS-1,5-4_1x04_P5.00mm_Horizontal | 2 | Screw_Terminal_01x04
15 | J11, J13 | TerminalBlock_Phoenix_MKDS-1,5-5_1x05_P5.00mm_Horizontal | 2 | Screw_Terminal_01x05
16 | J14 | PinSocket_1x03_P2.54mm_Vertical | 1 | GPIO
17 | J15 | PinSocket_1x04_P2.54mm_Vertical | 1 | SPI
18 | K3, K4 | TE_5-1393243-4 | 2 | RT424F12
19 | R1, R11, R19 | R_0805_2012Metric | 3 | 1K
20 | R2, R12 | R_0805_2012Metric | 2 | 1.8K
21 | R3, R5, R7, R9, R13, R15 | R_0805_2012Metric | 6 | 20K
22 | R4, R6, R8, R10, R14, R16, R20 | R_0805_2012Metric | 7 | 10K
23 | R17, R18 | R_0805_2012Metric | 2 | 5.1K
24 | SW1 | ANT23SECQE DPDT | 1 | Control 1
25 | SW2 | ANT23SECQE DPDT | 1 | Open_Close_1
26 | SW3 | ANT23SECQE DPDT | 1 | Control 2
27 | SW4 | ANT23SECQE DPDT | 1 | Open_Close_2
28 | SW5, SW6 | SW PTS636 SP50 SMTR LFS | 2 | SW_Push
29 | TP1 | TestPoint_Pad_1.5x1.5mm | 1 | GND
30 | TP2 | TestPoint_Pad_1.5x1.5mm | 1 | 12V+
31 | TP3 | TestPoint_Pad_1.5x1.5mm | 1 | 5V+
32 | TP4 | TestPoint_Pad_1.5x1.5mm | 1 | 3v3+
33 | U1, U4 | SOIC127P600X175-16N | 2 | ULN2003ADR
34 | U2 | Converter_DCDC_RECOM_R-78E-0.5_THT | 1 | R-783.3-1.0
35 | U3 | Converter_DCDC_RECOM_R-78E-0.5_THT | 1 | R-78E5.0-1.0
36 | U6 | ESP32-S3-WROOM-1 | 1 | ESP32-S3-WROOM-1

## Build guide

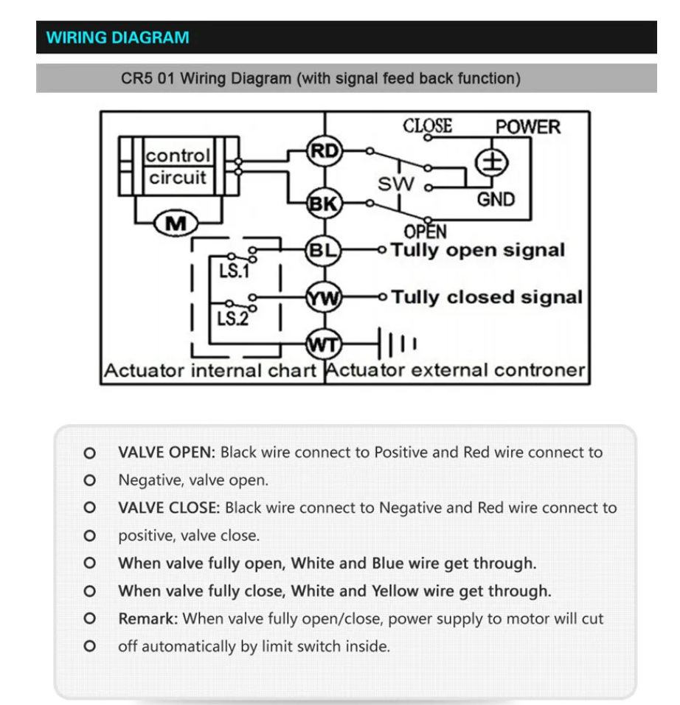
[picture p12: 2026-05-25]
docs/hardware/images/cr501-wiring-diagram.png

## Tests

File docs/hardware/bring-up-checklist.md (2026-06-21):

# Bring-Up Checklist

Use this checklist before connecting the system to permanent plumbing.

## Before power

- [ ] Inspect PCB for solder bridges.
- [ ] Check orientation of ESP32 module, USB-C connector, diodes, LEDs, relays, and regulators.
- [ ] Verify terminal blocks are installed correctly.
- [ ] Verify valve wiring matches `pinouts.md`.
- [ ] Verify panel LED wiring matches `breakaway-front-panel-controls.md`.
- [ ] Verify sensor wiring matches `pinouts.md`.

## First power

- [ ] Apply 12 V power.
- [ ] Measure the 12 V rail.
- [ ] Measure the 5 V rail.
- [ ] Measure the 3.3 V rail.
- [ ] Confirm ESP32 boots.
- [ ] Confirm no regulator or relay driver overheats.

## Valve test

- [ ] Test Valve 1 open command.
- [ ] Test Valve 1 close command.
- [ ] Confirm Valve 1 feedback changes at full open and full closed.
- [ ] Test Valve 2 open command.
- [ ] Test Valve 2 close command.
- [ ] Confirm Valve 2 feedback changes at full open and full closed.
- [ ] Test manual mode if the breakaway control board is installed.

## Sensor test

- [ ] Confirm Flow 1 pulses are detected.
- [ ] Confirm Flow 2 pulses are detected.
- [ ] Confirm Pressure 1 reading changes with pressure.
- [ ] Confirm Pressure 2 reading changes with pressure.

## Pressure-sensor calibration (per circuit)

The firmware ships with a factory-typical two-point linear fit shared
across both circuits. Real transducers drift up to ±3–5 % from that
fit; calibrating per-circuit eliminates the bias and makes the leak
test more sensitive.

Each circuit has four substitutions in
`firmware/esp-water-shut-off-3_10.yaml` (search for "PRESSURE
TRANSDUCER CALIBRATION"). Override them after bench measurement:

```yaml
substitutions:
  pressure_cal_main_zero_raw: "0.05"     # raw ADC at zero PSI
  pressure_cal_main_zero_psi: "0.0"      # calibrated PSI at zero_raw
  pressure_cal_main_max_raw:  "3.18"     # raw ADC at reference pressure
  pressure_cal_main_max_psi:  "100.0"    # gauge reading at max_raw
  # same four for the irrigation circuit (pressure_cal_irr_*)
```

Two-point procedure for one circuit:

- [ ] Disconnect (or ground) the transducer signal pin. Read the
      device's raw ADC voltage from Home Assistant — record as
      `zero_raw`. Record the corresponding PSI as `zero_psi`
      (typically a small negative number for a 0.5–4.5 V transducer
      whose lowest output doesn't quite hit 0 PSI).
- [ ] Connect a known reference: a hand pump with an analogue gauge
      teed into the line is the usual approach. Apply ~80–100 PSI
      (well above any typical household working pressure but inside
      the transducer's range). Read the raw ADC voltage — record as
      `max_raw`. Record the gauge's PSI as `max_psi`.
- [ ] Edit the four substitutions for that circuit. Re-flash. Confirm
      the live pressure reading now matches the gauge across the
      range.
- [ ] Repeat for the other circuit.

Cross-check: with both valves open and water static (no demand), the
two circuits should read within ~1–2 PSI of each other. If they
differ wildly, one transducer may be miswired, swapped, or faulty —
re-check before committing the calibration.

## Enclosure test

- [ ] Confirm panel LEDs indicate open and closed status.
- [ ] Confirm cable glands provide strain relief.
- [ ] Confirm wires are routed away from sharp edges.
- [ ] Confirm the front panel can open without pulling on wiring.

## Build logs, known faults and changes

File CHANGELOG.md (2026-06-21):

# Changelog

## [0.2.2] — 2026-06-21

A features + correctness + hardening release. Headlines: runtime per-circuit
flow-meter pulses-per-litre as a Home Assistant number entity (any meter, no
firmware edit) with a guided bucket / municipal-meter calibration helper;
a degraded-supply guard so events captured during pulsing municipal pressure
are flagged and stop poisoning clustering / hourly volume; a per-circuit
valve-type setting
(2-port / 3-port) so micro leak tests are correctly disabled on
drain-capable hardware; and a round of security and robustness work
covering CSRF, the autocorrelation primitive behind the supply detector,
and migration safety. Firmware credentials restored and a release-check
script added to keep them that way.

### New Features

- **Flow calibration helper (guided bucket / municipal-meter test)** — Settings → Flow Meter →
  "Calibrate…" walks the user through measuring the meter's TRUE pulses/litre: enter a known
  reference volume (a bucket, or the whole-house municipal-meter delta), run that fixture, and the
  add-on derives `new_ppl = current_ppl × (measured ÷ actual)` from the cumulative volume sensor
  (no firmware change; self-correcting even if the current PPL is far off). Runs pool by volume,
  with a method-aware sample gate (a >3% bucket correction needs ≥3 averaged fills to cancel
  fill error; a single ≥10-gal municipal run suffices) and a run-spread warning. Applying writes
  the firmware PPL entity; a small trim just re-scales the frozen anomaly thresholds (no relearn),
  a large change re-baselines. The deliberate test draw is suppressed from auto-shutoff and
  excluded from training/anomaly so it can't trip the valve or pollute the baseline. The
  result lists each run plus their average + range, and the suggested value is editable
  (re-gated on its own correction) before applying. New `routers/calibration.py` +
  `calibration_math.py`.
- **Runtime-configurable per-circuit flow meter (PPL)** — pulses-per-litre is now a
  per-circuit Home Assistant `number` entity (`Flow Meter PPL - <circuit>`), NVS-backed
  so it survives reboots and OTA updates. Set it to match any meter — turbine YF-B5 = 396,
  oval-gear ZJ-HSM-OFZATS-06 = 72, or any datasheet / bucket-tested value (replaces the old
  compile-time `flow_k_factor`). The per-circuit default is seeded at flash time by the
  `flow_ppl_main` / `flow_ppl_irr` substitutions, so a unit is correctly calibrated from first
  boot with no HA; `restore_value` then keeps the value across reboots and OTA updates, and it
  can be changed at runtime (HA / device web page) without a reflash. The firmware converts pulses→L/min
  from the live entity; the add-on reads it as the single source of truth (read-only in
  Settings) and derives each circuit's low-flow noise floor (60 ÷ ppl: ≈0.15 L/min at 396,
  ≈0.83 at 72). Changing the PPL forces a NON-destructive re-baseline of that circuit
  (auto-shutoff degrades to notify until the new baseline matures); historical event volumes
  are never recomputed. A coarse positive-displacement meter's small real draws are protected
  from the low-flow dribble-zeroing heuristic (which was tuned for the turbine). DB migration
  20260546 adds the `circuit_profile.pulses_per_litre` cache (default 396).
- **Degraded-supply guard** — when the municipal supply pulses, the
  paddlewheel flow sensor produces chaotic readings (forward and
  reverse pulses both count positive; brief zero-velocity transitions
  read as 0 L/min). Events captured during these conditions are now
  detected via pressure-band autocorrelation + flow-rectification
  signatures, flagged with `degraded_supply=1`, given an
  envelope-smoothed `volume_litres_effective` so daily totals stay
  sensible, and excluded from clustering. Surfaces in the History
  page with a filter, in the dashboard as a banner, and as a
  rate-limited HA notification.
- **Per-circuit valve type** — Setup wizard step 3b and Settings now
  ask whether each circuit is wired for a 2-port (standard) or 3-port
  (drain-capable, winterization-friendly) ball valve. 3-port circuits
  automatically skip the micro leak test (the drain port would always
  read as a constant leak); the schedule is preserved so switching
  back to 2-port resumes it. UI shows the reason on both the Device
  and Settings pages.

### Security

- **Per-session CSRF tokens** — the previous implementation cached a
  single token per process for an hour, so every browser session
  shared the same token. Replaced with stateless HMAC double-submit:
  a persistent server secret (generated once, never auto-rotated) +
  a per-browser `wm_session` cookie + `csrf_token = HMAC(secret,
  session_id)`. Setup-wizard POSTs are no longer CSRF-exempt (the
  earlier `startswith("/setup")` check let every `POST /setup/...`
  through with no token). Path-prefix exemptions replaced with
  exact-match for `/health` so `/health-anything` no longer slips
  past ingress checks.
- **Firmware credentials restored** — API encryption, OTA password,
  fallback-AP password and web-server auth are no longer commented
  out in the firmware YAML; all four read from `secrets.yaml` (see
  `firmware/secrets.yaml.example`). `dashboard_import` URL pinned
  to `@v3.10.0`. A new `scripts/check_firmware_release.py` script
  parses the YAML (not greps — commented examples don't fool it)
  and fails the release if any of those are missing or if the
  `dashboard_import` ref is mutable.

### Bug Fixes

- **Autocorrelation normalisation bug** — `_autocorr_at_lag` in the
  degraded-supply detector mismatched its numerator and denominator
  sample windows. The fix is a proper overlap-weighted Pearson
  correlation: each window centred by its own mean, normalised by
  `sqrt(var_head * var_tail)`, then scaled by sample overlap so the
  peak-pick prefers the fundamental over harmonics. The 12 existing
  degraded-supply tests still pass; 14 new tests in
  `test_autocorr.py` cover the primitive directly.
- **Migration rebuild safety** — the 20260526 migration's
  `hourly_volume` rebuild (DELETE + INSERT/SELECT from `events`) now
  uses a temp-table swap pattern wrapped in `try/except + rollback()`,
  so a Python-level exception mid-rebuild leaves the original table
  intact (previously safe only against process death, via SQLite's
  transaction durability). Eight new migration round-trip tests cover
  forward migration from every historical schema version,
  idempotency, rebuild correctness, and failure-injection.
- **Daily-summary UPSERT future-proofing** — `compute_daily_summary`
  now emits `ON CONFLICT … DO NOTHING` if the column-update list is
  ever empty (currently 12 columns; a future trim could make this a
  SQL syntax error otherwise).
- **Catch-up orphaned events longer than the check interval** — the
  periodic `historical_importer` catch-up advanced `last_check_ts` to
  `now` even while a flow period was still active, so an event longer
  than `CHECK_INTERVAL_MINUTES` had its start slide behind the checkpoint
  and could then only be recovered by a much-later startup backfill (a
  133-min irrigation run surfaced ~4 days late). `_import_range` now
  reports the trailing still-active flow start and folds it into
  `retry_from`, holding the checkpoint there until the event ends so the
  next catch-up after it closes reconstructs the full period. The overlap
  / UUID5 dedup keeps this from double-counting. New tests in
  `test_historical_importer_active_event.py`.
- **No-flow pressure phantoms blocked a circuit for hours** — a pure
  pressure transient whose pressure SETTLED below the recovery line (e.g.
  an irrigation zone solenoid nudging the steady pressure) never satisfied
  the pressure-recovery END and stayed open until the 6 h over-long
  watchdog; while open it blocked every new event on that circuit (the
  `_active_event is None` start gate), so the next irrigation run was
  missed by live detection. New `_maybe_close_settled_noflow`
  (`SETTLED_NOFLOW_CLOSE_S = 60 s`) closes such an event once pressure
  settles and flow has been zero ≥ 60 s; flow-triggered, pulsed, and
  ongoing draws are excluded so a real run is never cut short. New tests
  in `test_event_detector_pressure_recovery.py`.

### Performance

- **Async / blocking-SQLite audit** — `data_pruner.run` (nightly
  prune + daily-summary computation), `_run_waveform_purger` (daily
  DELETE), and `learn_best_hour` (60-day usage analysis for leak-test
  scheduling) are now offloaded via `loop.run_in_executor()` rather
  than running directly on the asyncio event loop. The orchestrator's
  `rebuild_from_db` / `backfill_unmatched` were already wrapped.

### Internal

- **Migration sequence** updated to schema version 20260527 (added
  `circuit_profile.valve_type` with a defensive backfill). Migration
  20260526 added 7 columns on `events`, the `event_waveforms` table,
  and rebuilt `hourly_volume` from events as the source of truth.
- **Set away mode** — `CASE WHEN ?` rewritten to explicit
  `CASE WHEN ? = 1` for clarity (same behaviour).
- **_enrich_from_waveform** docstring now lists the four A/B tracking
  fields it sets.
- **Firmware globals comment** stripped of stale 3.8.x slot+decimation
  history.

---

## [0.2.1] — 2026-05-24

A refinement release of the 0.2.x fixture-identification line. Headlines:
ESP-side waveform capture replaces software-only signatures, the event
detail modal makes individual events inspectable and re-labellable, auto
dark mode follows the OS, and the hardware documentation tree is now
complete (KiCad, BOM, bring-up checklist, build photos). Plus a long tail
of correctness work on the historical importer, propagation-delay scan,
clustering features, persistence, and CSRF coverage.

### New Features

- **Auto dark mode** — UI follows `prefers-color-scheme` automatically;
  no toggle, no setup. All pages, modals, toasts, status pills, and
  Chart.js charts switch live with the OS theme. The dark palette is
  derived from the existing OKLCH light tokens by lightness inversion,
  so brand identity is preserved.
- **ESP-side waveform capture and feature enrichment** — firmware 3.7.0+
  captures per-event flow and pressure waveforms on-device and streams
  them to the addon over a chunked HA event channel. The feature
  extractor uses them when overlap and quality are good enough, and
  falls back to the legacy software-derived values otherwise. Per-group
  fallback (metadata, start window, full window) so partial waveforms
  still help. Migration 031 adds four A/B tracking columns.
- **Event detail modal** on the History page — fixture re-assignment,
  ignore/restore, technical details (trigger type, peak flow, propagation
  delay, anomaly score), and an embedded waveform chart when ESP-side
  capture is available.
- **Merge clusters UI** on the Fixtures page — checkboxes on each
  cluster card plus a confirm page for combining fixtures the engine
  split apart.
- **Basic / Advanced split** in Settings — sidebar groups Advanced-only
  destinations behind a "Show Advanced" toggle persisted in localStorage.
  Per-circuit sub-tabs (Config / Detection / Advanced) replace the long
  scroll.
- **Re-run setup wizard** — Settings → Advanced → Re-run Setup
  unlocks the wizard after initial setup (e.g. for new hardware) and
  prompts to download a backup first. Setup re-locks automatically when
  the wizard completes.
- **Toast notification system** replacing inline status text.
- **Accessible valve confirm modal** replacing `window.confirm()` for
  open/close actions.
- **History page summary strip** showing event counts, pass/fail and
  totals at the top of the page.
- **Last automatic backup date** surfaced on the Backup page.
- **Irrigation enable/disable** toggle — hide the irrigation circuit
  from Dashboard and Device pages without removing it from
  configuration. Configured during setup (hardware selection step) and
  adjustable at any time in Settings → Home Profile. Backed by a new
  `circuit_profile.enabled` per-circuit flag that is forward-compatible
  with future multi-device setups.
- **Historical-import option** in the setup wizard — backfill events
  from HA history when first connecting to an existing device.

### Changes

- **Firmware bumped to v3.7+**. Per-event waveform capture; chunked
  streaming at native cadence; flow-rate publishes throttled to 4 Hz;
  valve-close re-trigger storm on fault fixed (main + irrigation);
  default logger level set to INFO.
- **Clustering**: 32-point pressure signature added to the feature
  vector (60 dims total). Feature weights retuned from F-ratio analysis
  on labelled events.
- **Event detection**: settled resting pressure now drives the event
  baseline; new pressure-transient shape features; zigzag algorithm for
  flow edges; medium sensitivity preset `pressure_drop_event_psi` default
  lowered 2.0 → 1.2 PSI (migration 027). Added pressure-recovery END
  for pulsed pressure-triggered events (e.g. fridge dispenser) so
  flow-pulse-onset flicker no longer fragments a single event.
- **Propagation-delay scan** reworked to be timestamp-based and
  observable in logs; under-estimation on gradual pressure drops fixed;
  pressure+flow composites now enriched with a real delay.
- **Leak test scheduling** now uses the local timezone instead of UTC,
  so the configured run hour matches your wall clock.
- **Flow-stop detection lag** reduced — EMA filter removed; sliding
  window dropped from 5 s to 2 s.

### Bug Fixes

- **Persistence**: `insert_event` is now an upsert, restore is atomic
  inside a single transaction, `UNIQUE (circuit, start_ts)` enforced.
  The historical importer no longer truncates active events on its
  next run (could lose multi-minute fixture activity). Migration 028
  collapses duplicate overlapping event rows left over from older
  builds.
- **Phantom events**: pressure-surge phantoms now rejected by both the
  live detector and the importer. Overnight pressure-oscillation
  phantoms eliminated via baseline-history requirements.
- **Security**: CSRF coverage tightened across all mutating methods
  (PATCH/PUT/DELETE, not just POST); `/setup` mutations locked
  post-setup so a stray `/setup/restore` can no longer wipe the live
  DB. Settings endpoint inputs hardened against malformed values.
- **Setup wizard could not be re-run** after initial setup — every
  `/setup/*` POST was silently redirected to the dashboard. Now shows
  a clear error banner pointing to Settings → Advanced → Re-run Setup,
  which deliberately re-opens the wizard after a confirmation step.
- **Reliability**: fire-and-forget tasks now tracked so failures
  surface; HA WebSocket reconnect is more robust (waveform onset bounds
  hardened, reconnect after setup wizard so new entity subscriptions
  activate immediately).
- **UI / UX**: setup progress bar `TypeError` on the "3b" sub-step
  fixed; dashboard chart legacy alias restored; XSS-via-fixture-label,
  valve modal race conditions, toast-timing edge cases and trickle
  status display all addressed (9 merge-readiness fixes).
- **Discovery**: circuit ID normalisation now survives Supervisor
  restarts (migration 024 patches stale `options.json`); reset-button,
  alert-switch and threshold roles added to role discovery; waveform
  role domains corrected (ESPHome text-sensor entities live in the
  `sensor.*` domain).
- **Database**: volume baselines now consistently UTC (fixes wrong
  daily / weekly totals on non-UTC servers); `update_data_retention`
  column allowlist prevents SQL injection via `**kwargs`.

### Hardware & Docs

- **PCB v1.2a** — design refresh with a new board image. KiCad project,
  Gerbers and BOM published under `docs/hardware/`.
- **Hardware build guide** now complete — overview, build order,
  pinout, bring-up checklist, and an 11-photo build gallery.
- **ESP32-S3-WROOM-1 pinout** diagram added to the hardware index.
- **Stylesheet cache-bust** — the `<link>` to `styles.css` now carries
  a `?v=0.2.1` query string so the UI picks up new CSS on upgrade
  without requiring a hard refresh.

### Internal

- Refactor: hardcoded circuit role names (`main`, `irrigation`)
  replaced with generic stable IDs (`circuit_1`, `circuit_2`) plus
  user-configurable display names. Migrations 023 / 024 carry existing
  installs across the rename.
- Shared restore logic extracted to `restore_utils.py` (used by both
  the setup-wizard restore and the Backup page).
- Migrations: 023 (circuit-ID rename), 024 (`options.json` patch),
  027 (sensitivity preset bump), 028 (overlap dedup), 031 (waveform
  A/B columns).
- Test suite expanded to 422 tests covering waveform enrichment,
  importer state-machine and 1 Hz resampling, propagation-delay
  scans, pressure-period detection, and discovery contracts.

---

## [0.2.0] — 2026-05-10

### Changes

- **Dashboard — "Past 7 days" volume** replaces the previous calendar-week
  (Monday-reset) total. The figure now reflects a rolling 7-day window,
  which is more useful day-to-day and avoids the sharp Monday drop to zero.
  Affects both the hourly-volume fallback path (SQL cutoff changed to
  `datetime('now', '-7 days')`) and the HA cumulative-sensor path (baseline
  key updated to midnight UTC 7 days ago). The volume baseline seeder in
  `_init_volume_baselines` was refactored to use a single naive-UTC key
  format throughout, fixing a key-format mismatch that would have silently
  broken daily totals on non-UTC servers.

- **Addon icon and logo** — `water_monitor/icon.png` (128 × 128) and
  `water_monitor/logo.png` (250 × 100) added. The generic puzzle-piece
  placeholder on the HA addon card and store detail page is now replaced by
  a proper branded icon.

- **Web UI favicon** — `favicon.ico` and `icon_32x32.png` added to the
  static assets folder. `base.html` now includes `<link rel="icon">` tags so
  the browser tab shows the addon icon instead of a blank page icon.

### Bug Fixes

#### Addon — robustness and correctness (second-pass audit)

- **`device_discovery.py` — `name_by_user` None crash in device search**:
  the exact-match path called `.lower()` on `name_by_user` without a None
  guard; the partial-match path already had one. Added `d.name_by_user and`
  guard for consistency.

- **`device_discovery.py` — `save_discovery` not transactional**: multiple
  `db.execute` calls (including FK-ordered deletes and circuit-entity inserts)
  were not wrapped in an explicit transaction. A mid-write failure left the
  DB in a partially-cleared state. Wrapped the entire function body in
  `with db:`.

- **`backup.py` — `tempfile.mktemp()` deprecated + connection leak**: the
  SQLite backup snapshot used the deprecated `mktemp()` (TOCTOU race
  possible). Replaced with `NamedTemporaryFile(delete=False)`. All three
  SQLite connections (`src_conn`, `mem_conn`, `disk_conn`) are now opened
  before a single `try/finally` block so none can leak if `backup()` raises.

- **`backup.py` — `QUICK_RESTORE_TABLES` missing two tables**:
  `fixture_ha_entity_map` and `fixture_daily_summary` were omitted, so
  HA entity mappings and daily fixture summaries were lost on a Quick Restore
  cycle. Both tables added to the list.

- **`database.py` — volume baselines used local time instead of UTC**:
  `compute_ha_daily_volume` and `compute_ha_weekly_volume` called
  `datetime.now()` (local) to compute the baseline `period_ts` key; SQLite's
  `'now'` is always UTC. On servers not in UTC this caused the key to miss
  the row seeded by `_init_volume_baselines`, falling back to a 0.0 baseline
  and showing the full cumulative sensor total as the daily/weekly figure.
  All baseline functions now use `datetime.now(timezone.utc)` with the
  `tzinfo` stripped before `isoformat()` to produce consistent naive-UTC
  keys throughout.

- **`database.py` — `update_data_retention` SQL column injection**:
  column names were interpolated from `**kwargs` without an allowlist. Added
  `_DATA_RETENTION_COLUMNS` frozenset; unknown keys raise `ValueError` before
  reaching the DB layer (mirrors the existing `_HOME_PROFILE_COLUMNS` pattern).

- **`settings.py` — `int(calibration_days)` raises 500 on bad input**:
  bare `int()` on a form value raises `ValueError` if the submission is
  non-numeric or empty. Added `try/except (ValueError, TypeError)` with
  fallback to 14 days.

- **`setup.py` — `int(cal_days)` raises 500 on non-numeric query param**:
  the setup-complete page renders `int(cal_days)` from a query parameter;
  a stale cache hit or crafted URL could pass a non-numeric string. Added
  `.isdigit()` guard with fallback to 14.

- **`main.py` — DB migration failure non-fatal**: a migration error was
  caught, logged at ERROR, and swallowed — the server started with a
  potentially broken schema. Now logs at CRITICAL and re-raises so the
  addon fails fast rather than running in a degraded state.

- **`orchestrator.py` — live-state cache used `setattr`**: per-circuit
  state was cached via `setattr(self, f"_live_state_{circuit}", ...)`.
  A circuit name colliding with an existing `Orchestrator` attribute would
  silently corrupt instance state. Replaced with a dedicated
  `_live_state_cache: Dict[str, Any] = {}`.

#### Addon — code quality (18-issue audit)

- **`device_discovery.py`** — removed duplicate `re.compile` call in
  `_find_entity_for_role`; replaced `__import__("datetime")` anti-pattern
  in `save_discovery` and `mark_setup_complete` with normal imports; added
  FK-safe delete ordering before `DELETE FROM fixtures` to prevent constraint
  violations on re-setup; added comments on regex fragility and suffix-list
  limitations.

- **`backup.py`** — wrapped `import_history_archive` multi-table writes in
  `with orch.db:` for atomicity; replaced `len(rows)` count (which included
  skipped duplicates) with before/after `COUNT(*)` for accurate inserted-row
  reporting; moved `arc.close()` to `finally`; removed dead `import io as _io`.

- **`settings.py`** — fixed `form.get("mqtt_publish_enabled")` truthy check:
  any non-empty string (including `"0"`) evaluated as `True`; changed to
  explicit `== "1"` comparison.

- **`setup.py`** — added `get_home_profile(orch.db) or {}` guard against
  `None` return before `dict()`; applied `quote_plus()` to all exception
  messages embedded in redirect URLs; added early-return guard when no
  restore options are selected.

- **`database.py`** — fixed `get_weekly_volume` SQL date expression that
  gave wrong results on Sunday and Monday (wrong `weekday 1` modifier);
  updated `_create_schema` `CREATE TABLE` statements to include columns
  added by migrations (self-documenting, fresh installs see full schema);
  added docstring to `dedup_events` explaining its post-restore role.

- **`orchestrator.py`** — unit-converted `volume_total` in the live-state
  dict using the same `vol_factor`/`vol_decimals` pattern as
  `volume_daily`/`volume_weekly`; removed startup `dedup_events()` call
  (migration 021's `UNIQUE` index prevents new duplicates at write time).

- **`historical_importer.py`** — `_rate_to_periods` now accepts an optional
  `query_end` parameter; an open flow period at the end of the query window
  is now closed at `query_end` rather than at the last reading timestamp,
  matching the `_onset_to_periods` behaviour.

- **`main.py`** — added inline comment explaining the `/setup` CSRF
  exemption trade-off.

#### Firmware — `esp-water-shut-off-3_6.yaml` (v3.6.0)

- **Spurious motor fault on concurrent close** (🔴): after `open_action`
  fires the relay and waits 15 s, it checks whether the open end-stop is
  inactive to detect a motor fault. If a `close_action` completed during
  that 15 s window the end-stop is naturally inactive — triggering a false
  fault. Fixed: the post-wait condition now checks
  `id(open_in_flight_*) && !id(open_end_stop_*).state` so a false fault
  can only fire if the open sequence is still genuinely in flight.

- **Pressure history buffer too small** (🔴): `pressure_history_main/irr`
  globals were 5-element `float[5]` arrays. `pressure_main` publishes at
  2 Hz (500 ms per sample), so the buffer held only 2.5 s of history, not
  the intended 5 s. Increased to `float[10]` (10 × 500 ms = 5 s); modulo
  index and initial value updated accordingly.

- **Close guard log message misleading** (🟡): fault-triggered close log
  said "valve is mid-travel opening" — incorrect when the guard is set after
  a failed close. Updated to "valve may be mid-travel or in recovery after a
  failed close".

- **Stale comments in `pressure_main_avg` and `pressure_main_fast`** (🟡/🔵):
  `pressure_main_avg` header comment still said "every 1 second", "1.25 s
  sliding window", "30-sample", "120 bytes" — all wrong after the 2 Hz
  refactor. Corrected to 500 ms / 50-sample / 25 s / 200 bytes.
  `pressure_main_fast` comment said "slower 1 Hz pressure_main" — corrected
  to 2 Hz.

---

## [0.2.0-rc2] — 2026-05-08

### Bug Fixes

#### Event-table deduplication (migration 021)

Three independent bugs combined to produce many duplicate event rows in the
database — visible in Quick Restore backups as 8–9 identical rows per event
with different `id` values and `created_at` timestamps spanning several days.

**Root causes:**

1. **Pre-fix code generated UUID4 ids.** Before the `uuid5` fix in
   `feature_extractor.py`, every re-processing of the same raw event produced
   a fresh random id. `INSERT OR REPLACE` was keyed on `id` (PRIMARY KEY)
   only — no `UNIQUE` constraint on `(circuit, start_ts)` — so every import
   created a new row.

2. **`event_exists_near()` was broken.** The historical importer calls this
   to skip already-imported events. The implementation used SQLite's
   `datetime()` function which returns `'YYYY-MM-DD HH:MM:SS'` (space
   separator), while stored `start_ts` values use ISO 8601 `'T'` separator.
   ASCII `'T'` (84) > `' '` (32), so the upper-bound string comparison
   always failed and every event was re-imported on every catch-up cycle.

3. **Migration 015 was one-shot.** It deduped correctly but only ran once.
   Quick Restore used `INSERT OR REPLACE` keyed on `id`, so pre-fix backups
   re-introduced duplicates on restore, and migration 015 never ran again.

**Fixes in this release:**

- **Migration 021** — normalizes all `events.start_ts` / `end_ts` to UTC
  ISO 8601 (`+00:00`), recomputes UUID5 `id` values against the new UTC
  timestamps (prevents future `fixture_id` loss on re-import), clears
  `cluster_id` on dedup survivors so `backfill_unmatched` re-matches them,
  removes duplicate rows (keeps `MAX(rowid)` — newest insert), drops the
  superseded `idx_events_circuit_ts` index, and creates
  `UNIQUE INDEX idx_events_circuit_start_unique ON events (circuit, start_ts)`.
  Same UTC normalization applied to `hourly_volume.hour_ts`. Entire migration
  is wrapped in a transaction for atomicity.

- **`event_exists_near()`** — rewritten to compare in Unix epoch seconds via
  `CAST(strftime('%s', start_ts) AS INTEGER) BETWEEN lo AND hi`. This is
  robust against separator mismatch, mixed timezone offsets, and microsecond
  precision differences. Added `AND start_ts IS NOT NULL` guard.

- **`extract_features()`** — normalizes `event.start_ts` / `end_ts` to UTC
  before storing and before computing the UUID5 id. Same event expressed
  in any timezone now always produces the same id and the same stored string.

- **Startup dedup** — `dedup_events()` called in `orchestrator.py` after
  migrations as a safety net for any legacy data that slipped through. No-op
  on clean databases.

- **Quick Restore** — after importing events, `normalize_events_utc()` runs
  first (order matters), then `dedup_events()`. Export query now uses
  `ORDER BY rowid ASC` so the newest row for each `(circuit, start_ts)` is
  last in the JSON array and wins on `INSERT OR REPLACE`.

- **Test suite** — 12 new tests in `test_event_dedup.py` covering dedup
  semantics, UNIQUE constraint, `event_exists_near` correctness (including
  the regression test that fails on the old code), DST offset mismatch,
  `normalize_events_utc`, and the migration 021 end-to-end path.

#### Additional bug fixes (codebase audit)

- **`leak_test_scheduler.py` — `dir()` guard always True / missing column**
  (`BUG-01`): `'schedule' not in dir()` evaluates against the object's
  *attributes*, not local variables, so it was always `True` — the duration
  block never ran. `schedule["duration_minutes"]` then caused a `KeyError`
  because the `leak_test_schedules` table has no such column. Fixed: removed
  the bogus guard, fetch duration from the HA firmware entity instead, and
  initialize `result_str = "unknown"` before the poll loop so a timeout log
  message can't fail with `UnboundLocalError`.

- **`event_detector.py` — silent event loss on full queue** (`BUG-02`):
  `asyncio.create_task(queue.put(ev))` silently blocks (and leaks a task)
  when the queue is full, dropping the event with no log. Changed to
  `queue.put_nowait()` with an explicit `QueueFull` warning log.

- **`presence_watcher.py` — false away-mode at startup** (`BUG-03`):
  Python's `all([])` returns `True`, so the watcher enabled away mode at
  startup before HA had delivered any entity states. Added a guard: skip
  evaluation if no entity states are known yet.

- **`routers/backup.py` — partial restore wipes data permanently** (`BUG-04`):
  The Quick Restore loop deleted tables then re-inserted rows with only one
  `db.commit()` at the end. A failure mid-loop left the database in an
  inconsistent state with no rollback path. Wrapped the entire loop in
  `with db:` (atomic transaction).

- **`fixture_publisher.py` — SQLite thread-safety violation** (`BUG-05`):
  paho-mqtt's `_on_connect` callback runs on paho's background thread but
  called `_publish_all_confirmed_sync()` directly, reading `self._db` from
  the wrong thread. Moved the call to
  `loop.call_soon_threadsafe(_publish_all_confirmed_sync)` so it runs on the
  asyncio event loop thread that owns the connection.

- **`feature_extractor.py` — `hour_ts` format inconsistency** (`BUG-06`):
  `hour_ts` was stored via `.isoformat()` on a UTC-aware datetime, producing
  `'2026-05-03T17:00:00+00:00'`. All DB queries use SQLite's
  `strftime('%Y-%m-%dT%H:00:00', …)` which produces no timezone suffix,
  causing lexicographic comparisons to fail. Changed storage to
  `strftime('%Y-%m-%dT%H:00:00')`. Migration 021's `hourly_volume.hour_ts`
  normalization pass updated to use the same no-suffix format for consistency.

- **`routers/settings.py` — event loop blocked during prune** (`BUG-07`):
  `orch.data_pruner.prune_now()` runs synchronous SQLite `DELETE` statements
  that can take several seconds on large tables, blocking the asyncio event
  loop. Moved to `await loop.run_in_executor(None, prune_now)`.

- **`routers/setup.py` — OOM risk + unatomic restore** (`BUG-08`):
  `await file.read()` had no size limit — a multi-GB upload would exhaust
  memory. Added the same 50 MB cap as the main backup restore endpoint.
  The restore loop was also unprotected (same partial-failure risk as
  BUG-04). Wrapped in `with db:`. Added `normalize_events_utc()` +
  `dedup_events()` after events import (same as the main restore path).

#### Second-tier bug fixes and suspicious-pattern cleanup

- **`orchestrator.py` — zero sensitivity thresholds silently reset to preset**
  (`BUG-09`): `_get_sensitivity` used `row[x] or preset[x]` to merge DB
  values with preset defaults. `0.0` is falsy, so a user-set threshold of
  `0.0` (valid — disables a trigger) always reverted to the preset. Changed
  to `value if value is not None else preset[key]`.

- **`event_detector.py` — pressure recalculation skipped for zero-baseline
  systems** (`BUG-12`): `if ev.pre_event_pressure_psi` is falsy when baseline
  is 0.0, so min/delta pressure were never recomputed for unpressurised
  systems. Changed to `is not None`.

- **`main.py` — leaked DB connection after migrations** (`BUG-13`): `lifespan`
  opens a connection, runs migrations, then discards it without closing. The
  abandoned handle held a shared lock and prevented WAL checkpointing.
  Wrapped in `try/finally: _db.close()`.

- **`data_pruner.py` — stale daily summaries never recomputed** (`BUG-14`):
  `ds.computed_at < date(e.start_ts, '+1 day')` compares a full ISO timestamp
  string against a plain `YYYY-MM-DD` string. `'T' (84) > '-' (32)` in ASCII,
  so same-day rows were never considered stale. Wrapped `computed_at` in
  `date()` for a clean date-vs-date comparison.

- **`ha_client.py` — WebSocket recv loops hang forever on network stall**
  (`BUG-15`): `_subscribe_state_changed` and `ws_request` used unbounded
  `while True: await ws.recv()` loops with no timeout. A network stall during
  connection setup or a one-shot query would block the event loop indefinitely.
  Added `asyncio.wait_for(ws.recv(), timeout=15/30)` with descriptive
  `TimeoutError` messages.

- **`historical_importer.py` — import hangs on full event queue** (`BUG-16`):
  `await self._event_queue.put(raw)` blocks forever when the queue is full
  (identical pattern to BUG-02). Changed to `put_nowait` with a `QueueFull`
  warning; dropped events are re-attempted on the next catch-up cycle.

- **`feature_extractor.py` — anomaly alert branch permanently dead code**
  (`BUG-17`): `features.get("anomaly_score")` was always `None/absent` because
  nothing set it — the alert check after `_cluster_event` never fired.
  `_cluster_event` now derives `anomaly_score = 1.0 - match_confidence` from
  the cluster match result and stores it in `features`. Events rejected by
  type-gate or excluded from training do not set the score (they are not
  anomalous — they are simply not yet matched).

- **`training_manager.py` — full recalibration leaves stale confirmed
  centroids** (`BUG-19`): `trigger_full_recalibration` cleared events and
  volume data but not `fixture_clusters`. The in-memory DBSTREAM was reset by
  `start_calibration → reset_circuit`, leaving confirmed centroid rows in the
  DB with no in-memory counterpart. New events were then type-gate-rejected
  instead of matched. Added `("fixture_clusters", "circuit")` to the deletion
  list so the DB and engine state are always consistent after a full reset.

- **`routers/settings.py` — non-numeric retention form input raises 500**
  (`BUG-20`): bare `int(form.get("events_retain_years", 1))` raises
  `ValueError` on any non-numeric or empty submission. Added a local `_int()`
  helper that returns the default on conversion failure.

- **`database.py` — `update_home_profile` SQL injection via unvalidated keys**
  (`SUSP-02`): column names were interpolated directly into SQL from `kwargs`
  with no allowlist. Added `_HOME_PROFILE_COLUMNS` frozenset; unknown keys
  raise `ValueError` before reaching the DB layer.

- **`device_discovery.py` — deprecated `datetime.utcnow()`** (`SUSP-06`):
  replaced two `datetime.utcnow().isoformat()` calls with timezone-aware
  `datetime.now(timezone.utc).isoformat()`.

- **`routers/setup.py` — form circuit/role written to DB without validation**
  (`SUSP-07`): any form field containing `__` was split into `circuit__role`
  and written directly to `circuit_entity_map`. Added validation against
  `ROLE_PATTERNS` (the authoritative allowlist from `device_discovery.py`);
  unknown circuit or role pairs are logged and skipped.

- **`main.py` — `import re` on every request** (`SUSP-09`): `import re`
  was inside the middleware function body, re-executed on every HTTP request.
  Moved to module level (`import re as _re`).

---

## [0.2.0-rc1] — 2026-05-08

### New Features

#### Phase 2.1 — Labelling state + clean-start guarantee

- **Three-stage training lifecycle** — calibration now ends in a
  ``labelling`` review window (was: auto-promotion straight to ``live``).
  After training, the user confirms detected clusters on the Fixtures page,
  then explicitly clicks **Activate fixtures** to transition to ``live``.
  This was the missing state from the original training-manager design,
  deferred from Phase 1 and now reinstated. Anomaly detection is held off
  until activation so the live phase doesn't run against unconfirmed
  clusters.
- **Auto-activation safety net** — if a circuit sits in ``labelling`` for
  more than 7 days without user review (``LABELLING_AUTO_TIMEOUT_DAYS``),
  ``_check_progress`` auto-promotes it to ``live`` and sends an HA
  notification. Prevents the system being stuck waiting for the user to
  come back.
- **Clean-start guarantee** — ``start_calibration`` now deletes orphan
  clusters (``fixture_clusters`` rows with ``fixture_id IS NULL``) from
  any prior calibration cycle and calls ``cluster_engine.reset_circuit()``
  to flush the in-memory DBSTREAM and StandardScaler. Confirmed clusters
  (user-labelled fixtures) survive recalibration.
- **Recalibrate from labelling** — ``start_calibration`` accepts
  ``labelling`` as a valid source state, so a user reviewing clusters who
  doesn't like what they see can trigger recalibration directly without
  resetting to idle first.
- **Fixtures page UI** — per-circuit "Awaiting review" pill, a callout
  card with the **Activate fixtures** button, and adapted banner copy
  ("confirm below, then activate the circuit") when any circuit is in
  labelling. Settings page badge/pill render in amber for labelling.
- **Banner-count fix (carried into this release)** — the unreviewed-clusters
  banner now only counts clusters whose grid is actually rendered, fixing
  the contradiction where calibrating circuits with latent clusters showed
  "*N* clusters need review" with nothing visible to review.
- **Test suite** — 10 new tests in ``test_training_state.py`` covering
  orphan clearing, confirmed-cluster preservation, calibrating →
  labelling → live transitions, no-op activate from wrong states,
  auto-timeout firing at 8 days and not firing at 6 days,
  ``percent_complete=100`` for labelling, HA sensor publishing, and
  recalibrating from labelling. Total suite is now 33 tests.

#### Phase 2.1 — Type-aware fixture matching (Commits 1–4 complete)

- **Per-fixture-type variance profiles** — `fixtures.py` gains
  `FIXTURE_VARIANCE_PROFILES` and `FIXTURE_MATCH_THRESHOLDS` for all 23
  fixture types. Deterministic fixtures (toilet, ice maker, refrigerator)
  have tight thresholds (0.5–0.7); user-driven fixtures (shower, taps) use
  loose thresholds (1.8–2.8) with duration and volume as "float" features
  that are zeroed from the distance calculation; programme-driven appliances
  (washing machine, dishwasher) are loosest (2.5–3.0).
- **Type-aware match gate** — once a cluster is confirmed as a fixture type
  the engine uses per-type weighted Euclidean distance (anchor features
  amplified, float features ignored) against the stored centroid. Events that
  exceed the per-type threshold are rejected with reason
  ``'type_gate_rejected'`` and their ``cluster_id`` stays NULL so
  ``backfill_unmatched`` can retry them if the threshold is later relaxed.
  Unconfirmed clusters keep the existing global-threshold behaviour.
- **Live cache invalidation** — confirming or deleting a cluster on the
  Fixtures page immediately updates the in-memory type cache via
  ``notify_fixture_confirmed`` / ``notify_fixture_removed``. No restart
  required. The cache is also rebuilt from DB on every ``rebuild_from_db``
  call as a drift guard.
- **Rebuild-mapping tightened** — ``_rebuild_id_map_from_centroids`` now
  uses the per-type threshold (not 2× global) as the acceptance bound when
  re-attaching a river center to a confirmed DB cluster after a rebuild.
- **``events.match_rejection_reason``** — new TEXT column recording why an
  event has ``cluster_id IS NULL``: ``'features_missing'``,
  ``'no_centers'``, or ``'type_gate_rejected'``. Added via idempotent
  ``ALTER TABLE`` migration so existing databases are upgraded automatically
  on first start.
- **Schema bugfix** — ``fixture_clusters.centroid`` and
  ``.feature_std`` gained ``DEFAULT '{}'`` so the intermediate INSERT in
  ``_upsert_cluster`` no longer violates the NOT NULL constraint on fresh
  databases.
- **Test suite** — 17 unit tests in ``water_monitor/tests/`` covering the
  weighted-distance helper, type cache lifecycle, gate acceptance/rejection
  for toilet and shower, unconfirmed regression guard, schema-drift guard,
  multi-circuit isolation, and fail-open behaviour on corrupt centroids. Run
  with ``pytest water_monitor/tests/``. Requires ``pytest`` from
  ``requirements-dev.txt`` (not installed in the Docker image).

#### Phase 2.1 — Fixture Identification (Stages 1–2 complete)

- **Online clustering engine** — `cluster_engine.py` runs per-circuit
  `river.DBSTREAM` + `StandardScaler` (online, density-based, no fixed K).
  Every new water event is matched to a cluster immediately as it arrives.
  Startup replays the last 60 days of matched events to reconstruct
  in-memory state without pickling (see ADR 008).
- **9-feature event vectors** — `avg_flow_lpm`, `peak_flow_lpm`,
  `duration_seconds`, `volume_litres`, `pressure_delta_psi`,
  `has_pressure_transient`, `flow_variability`, `hour_sin`, `hour_cos`.
  Time-of-day is sin/cos encoded so midnight and 11 pm are adjacent in
  feature space.
- **Sequence context** — each event records `seconds_since_prev_event` and
  `prev_cluster_id`; the previous event gets `seconds_to_next_event` filled
  retroactively. Groundwork for Stage 3 cooccurrence boost.
- **Cluster confidence progression** — three levels persisted on
  `fixture_clusters.confidence_level`: preliminary (< 50 events), learning
  (50–200), confirmed (200+ or user-locked). See ADR 009.
- **Heuristic type suggestion** — `suggest_fixture_type` runs at event 1
  and every 10 events per cluster, updating `suggested_type` and
  `suggested_confidence`.
- **Fixtures page** — shows all clusters grouped by circuit with confidence
  pills, avg stats (unit-converted), and a confirm/name flow that creates a
  `fixtures` row and back-fills `events.fixture_id`. "Re-run clustering"
  rebuilds DBSTREAM state from the last 60 days.
- **Settings unit conversion for ESP device entities** — flow threshold and
  pressure threshold entities now display and accept values in the user's
  chosen units (gal/min, bar, etc.) and convert back to L/min / PSI before
  sending to HA/ESP.
- **Duplicate event prevention** — events use a deterministic
  `uuid5(circuit/start_ts)` ID so the same event can never be inserted twice.
  Migration 015 removes any existing duplicates on first run.
- **Migration 016** — adds `idx_events_fixture_id` and `idx_fixtures_circuit`
  indexes for Phase 2 query paths.

#### Design refresh

- Full visual refresh across all 7 pages (Dashboard, Device, History,
  Fixtures, Settings, Backup, Setup) — OKLCH colour tokens, consistent
  card/pill/button components, Settings sidebar navigation.

---

## [0.1.2] — 2026-05-03

### Removed
- **Water Budget & Cost** — Removed entirely. HA's built-in `utility_meter` integration
  provides a richer and better-maintained implementation. The three database columns
  (`monthly_budget_litres`, `water_cost_per_litre`, `water_cost_currency`) are dropped
  automatically by migration 012 on first start.

### Additional Bug Fixes (post-release)

- **`UnboundLocalError: cannot access local variable 'orch_ref'`** — In
  `IngressTemplates.TemplateResponse`, `orch_ref` was only assigned inside the
  CSRF cache-refresh block; when the cache was still warm the variable was never
  set and the unit context injection crashed. Fixed by hoisting the lookup before
  the cache block so it is always defined.
- **Backup restore failed with removed budget columns** — The setup wizard's own
  restore loop used raw column names from the backup JSON without schema validation.
  Old backups containing `monthly_budget_litres` / `water_cost_per_litre` /
  `water_cost_currency` caused an `OperationalError` because migration 012 had
  already dropped those columns. Fixed by applying the same `PRAGMA table_info`
  column-filtering used in the main backup restore route.
- **Units reverted to L/min after backup restore** — `_init_display_units` ran at
  startup (before the restore) and correctly detected `gal/min + psi`; the subsequent
  backup restore overwrote `home_profile.flow_unit` with the backup's schema-default
  `L/min`. Fixed by re-running `_init_display_units` (and invalidating the unit cache)
  immediately after the restore completes — the skip condition preserves any
  explicitly-chosen units from the backup while re-detecting when only defaults were
  stored.

### New Features

#### Display Unit Conversion
- **Unit selection step in setup wizard** — Step 4 of the setup wizard asks the user
  to confirm or change the auto-detected units before proceeding to home details.
  Applies to both new setup and backup restore paths. Units can still be changed
  at any time in Settings → Display Units.
- **Configurable flow and pressure units** — Dashboard, history, device page, leak test
  results, and HA push notifications all respect the user's chosen units
  - Flow rate and volume: L/min · gal/min · ft³/min · m³/min
  - Pressure: PSI · bar · kPa
- **HA unit system auto-detection** — On first run, queries `/api/config` and selects
  sensible defaults (US installs get gal/min + PSI; metric installs get L/min + bar).
  User overrides are preserved across restarts.
- **Re-detect from HA button** — Settings page lets users re-query HA at any time.
- **30-second result cache** — `load_unit_context` caches the DB read; invalidated
  immediately on save so the next page load reflects the change without delay.

#### Historical Event Import
- **Startup backfill** — On every restart, reconstructs events missed while the addon
  was offline (up to 10 days of HA recorder history).
- **Periodic catch-up** — Runs every 30 minutes to fill gaps from brief restarts.
- **Dual detection strategy** — `flow_pulse_onset` transitions as primary signal with
  15-second gap bridging; `flow_rate > 0.05 L/min` sustained readings as fallback.
- **Pressure fidelity** — Prefers `pressure_main` (2 Hz, 1.375 s smoothing) over
  `pressure_main_avg` (25 s smoothing) for historical pressure data.
- **Duplicate prevention** — Checks ±30 seconds before inserting; safe to re-run.
- **Concurrent query limit** — At most 2 simultaneous HA WebSocket history queries.

#### Cross-Circuit Valve State
- **`other_valve_open` event field** — Live state of every other circuit's valve is
  captured when each event starts. Main-circuit events with `other_valve_open = true`
  are almost certainly irrigation bleed-through — a direct binary feature for Phase 2.

#### Firmware Changes (`esp-water-shut-off-3_4.yaml`)
- **`pressure_main` / `pressure_irrigation` changed from `diagnostic` to normal** —
  HA recorder now logs them at 2 Hz. Used for historical import pressure fidelity and
  for the live dashboard reading (12× more responsive than the 25 s averaged sensor).

### Bug Fixes

#### Unit Conversion
- Hourly chart bars, total, and tooltip not multiplied by `vol_factor`
- `device.html` status strip and threshold labels were hardcoded `PSI` / `L/min`
- Leak test `baseline_psi` / `final_psi` not multiplied by `pressure_factor`
- Event table used fixed `%.2f`/`%.1f` format strings; now respects `*_decimals`
- Sensitivity threshold label hardcoded as `(PSI)`
- Alert push notifications always used PSI and L/min regardless of user units
- Auto-detect skip condition only checked `flow_unit`; manual `pressure_unit` change
  was overwritten on restart — now checks both columns against schema defaults
- Fallback pressure unit for unrecognised HA volume units was `psi`; changed to `bar`
- Pressure dropdown showed raw key `"psi"` instead of friendly label `"PSI"`
- Budget section not fully removed from dashboard template and route
- `load_unit_context` hit the DB on every 2-second poll (60+ reads/min)
- `_init_display_units` silently did nothing on fresh install (UPDATE on missing row)

#### Core
- Timezone mismatch in daily volume baseline (`period_ts` used UTC vs local midnight)
- Full recalibration left stale `daily_summary`, `import_state`, `volume_snapshots`
- Away mode calibration timer used per-loop 1-minute extension instead of true elapsed
  away duration; offline time was not accounted for
- PresenceWatcher created unbounded concurrent tasks on rapid entity state changes
- Data pruner `_wait_until_3am` was not DST-safe; now recalculates in 1-hour chunks
- Historical importer closed an ongoing event at `history[-1]` (could equal start);
  now closes at the original `query_end`
- Backup restore interpolated JSON column names directly into SQL (injection risk)
- No file size limit before parsing uploaded backup JSON (OOM risk on large files)
- `X-Ingress-Path` header embedded unescaped in setup-redirect HTML
- `start_calibration` rejected `"calibrating"` as starting state (broke backup restore)
- Pruner training fence used `> calibration_ends_at` protecting all pre-install history;
  now uses `BETWEEN started_at AND calibration_ends_at`
- Leak test could poll forever if firmware changed a terminal result string; now has a
  hard timeout with a clear warning log
- Daily volume showed 0 — baseline was set to `current_ha_value`, making delta zero
- Dashboard `| round()` Jinja2 filter crashed on string values from HA states
- `Unexpected token '&'` JS error on all pages — `tojson` filter returned plain `str`
  instead of `Markup`, allowing autoescape to corrupt JSON inside `<script>` blocks
- 500 on dashboard after setup — inline `from ..database` used double-dot path

### Performance and Reliability
- Long-event memory — pressure and flow readings downsampled after 120 s (keep every
  5th); a 2-hour irrigation run drops from ~290 k to ~35 k samples
- `get_write_lock()` exported from `database.py` for multi-step async write sequences

---

## [0.1.1] — 2026-05-03

### Bug Fixes
- Valve button shows correct state after live poll
- Leak test countdown uses actual configured duration
- Leak test results correctly written to database
- Abort leak test clears `is_running()` state immediately
- Valve shows correct Open/Close button during leak test
- Duplicate abort button removed from dashboard
- Settings page 500 — `SENSITIVITY_PRESETS` imported inside function
- Fault/trickle reset buttons had missing device prefix
- Setup redirect broken behind HA ingress proxy
- Firmware router import from wrong module
- `training_manager` None-guard missing on startup
- `asyncio.gather()` indentation error in orchestrator
- Volume display showed "0 LL" (unit suffix applied twice)
- Setup wizard `from __future__` mid-file SyntaxError

### New Features

#### Dashboard
- Live valve state polling every 5 seconds without page reload
- Safety fault confirmation dialog before valve open override
- Away mode banner

#### Leak Test
- Countdown timer with settle phase display
- Learned quiet hour scheduling from 60-day usage history
- Manual triggers start immediately; single-click abort

#### History Page
- Daily usage bar chart with anomaly overlay
- Range buttons: 30d / 6m / 1y / All / This month / This year / Year-over-year
- Custom date range filter

#### Settings
- Away / Vacation mode with calibration timer extension
- HA presence linking (person, device_tracker, input_boolean, alarm_control_panel)
- Mobile push notifications to `notify.mobile_app_*` services
- Data retention sliders (events and hourly volumes)
- Automatic weekly backup to `/share/water_monitor_backups/`
- Recalibration backup prompt

#### Backup and Restore
- Three-tier backup: Quick Restore JSON · History Archive SQLite · Full ZIP
- Setup wizard restore from backup (step 0)

#### Alerts
- AlertManager wires alert toggles to HA notifications and mobile push

#### Security
- CSRF protection on all state-changing form POSTs

#### ESP Firmware
- Fault reason text sensors with human-readable strings
- Six fault trigger types covered

---

## [0.1.0] — Initial release

- ESP32-S3 water monitor integration for Home Assistant
- Dual-circuit support (main + irrigation motorised ball valves)
- Real-time pressure and flow monitoring via ESPHome entities
- Setup wizard with automatic device and entity discovery
- Valve open/close control with live state updates
- Micro leak test scheduling and manual trigger
- Safety fault detection and reset
- Training/calibration state machine
- Basic dashboard with circuit status cards
- Settings page with sensitivity presets and alert configuration
- History page with leak test results and event log

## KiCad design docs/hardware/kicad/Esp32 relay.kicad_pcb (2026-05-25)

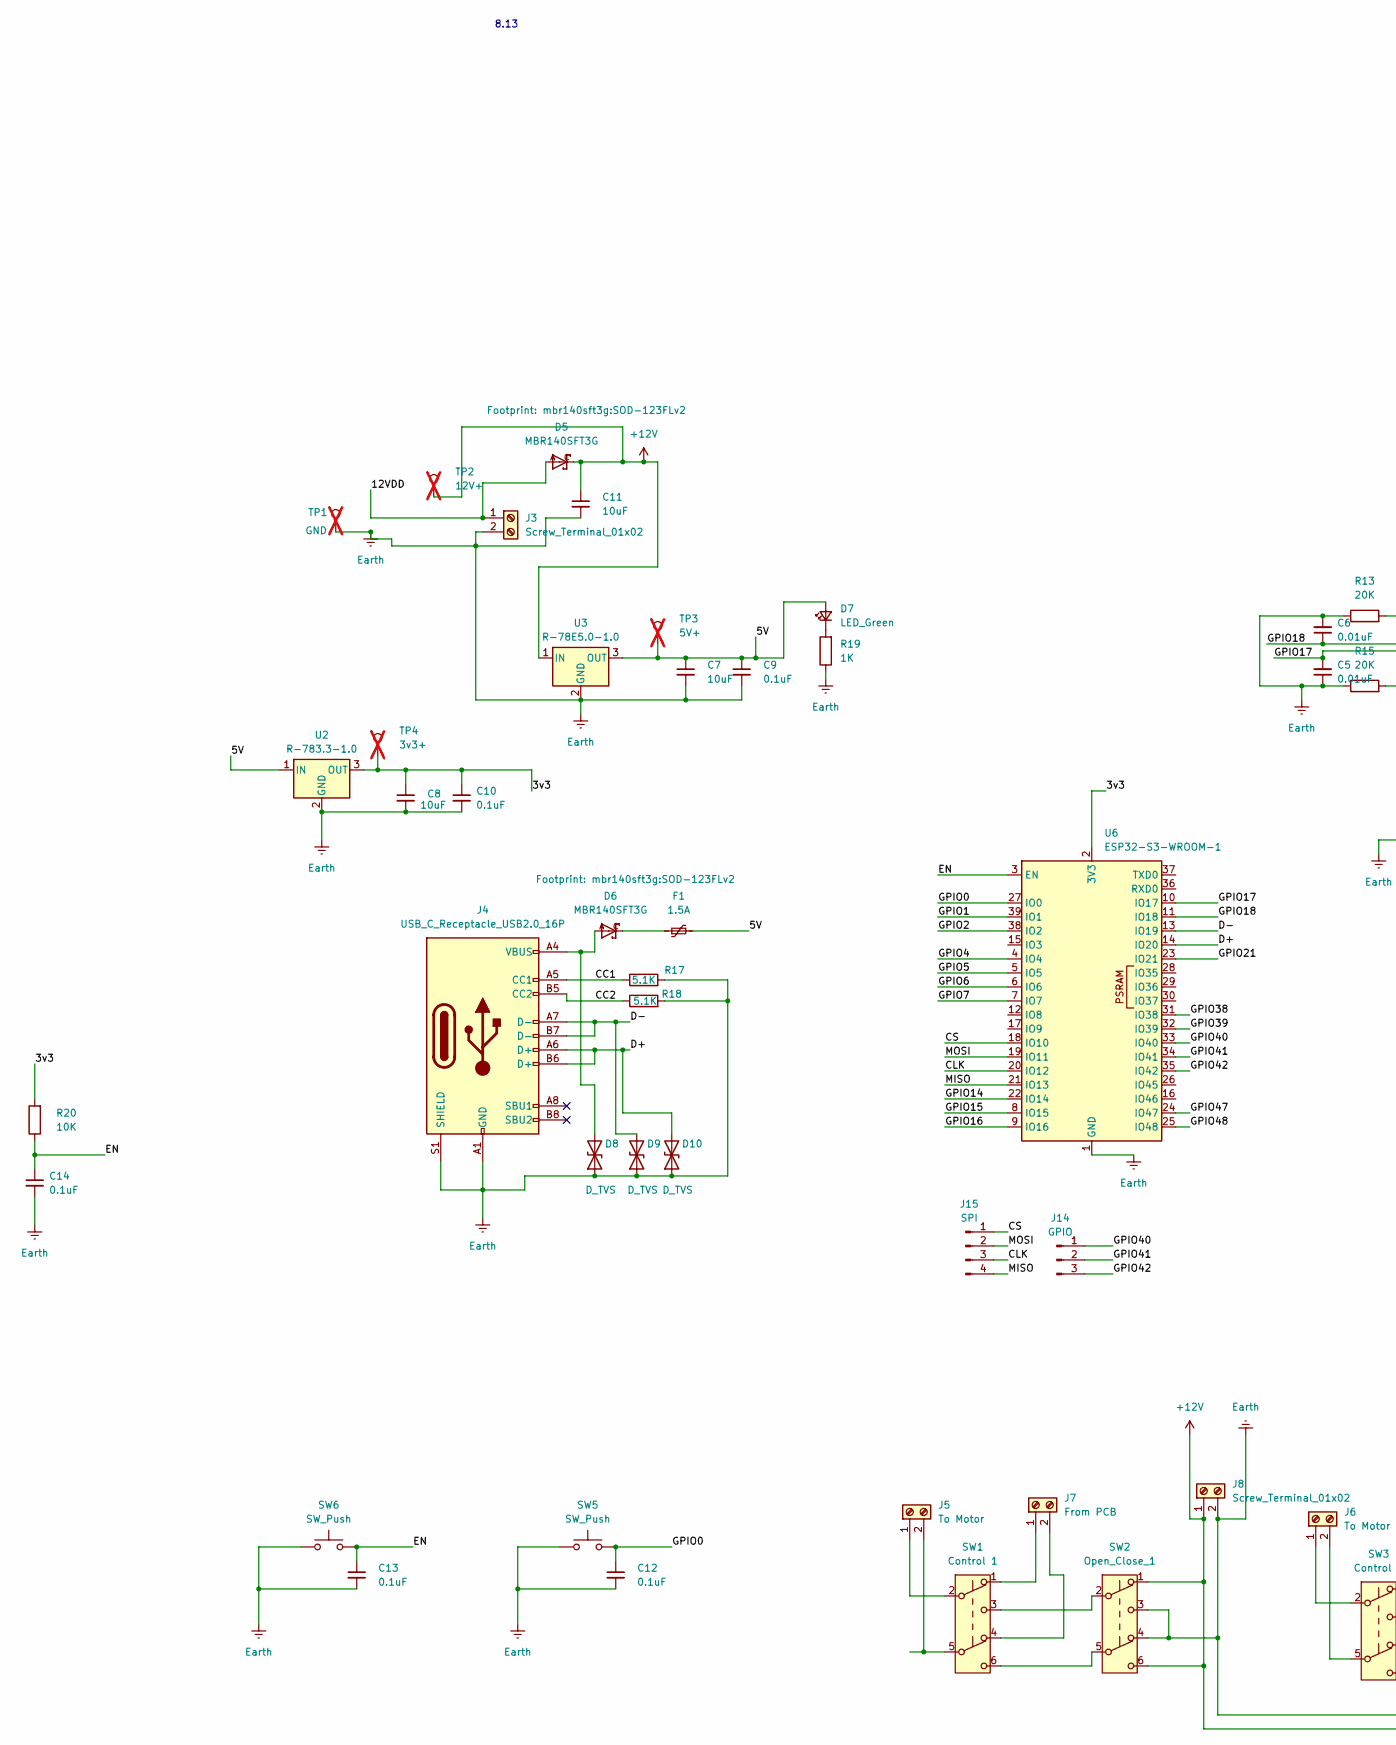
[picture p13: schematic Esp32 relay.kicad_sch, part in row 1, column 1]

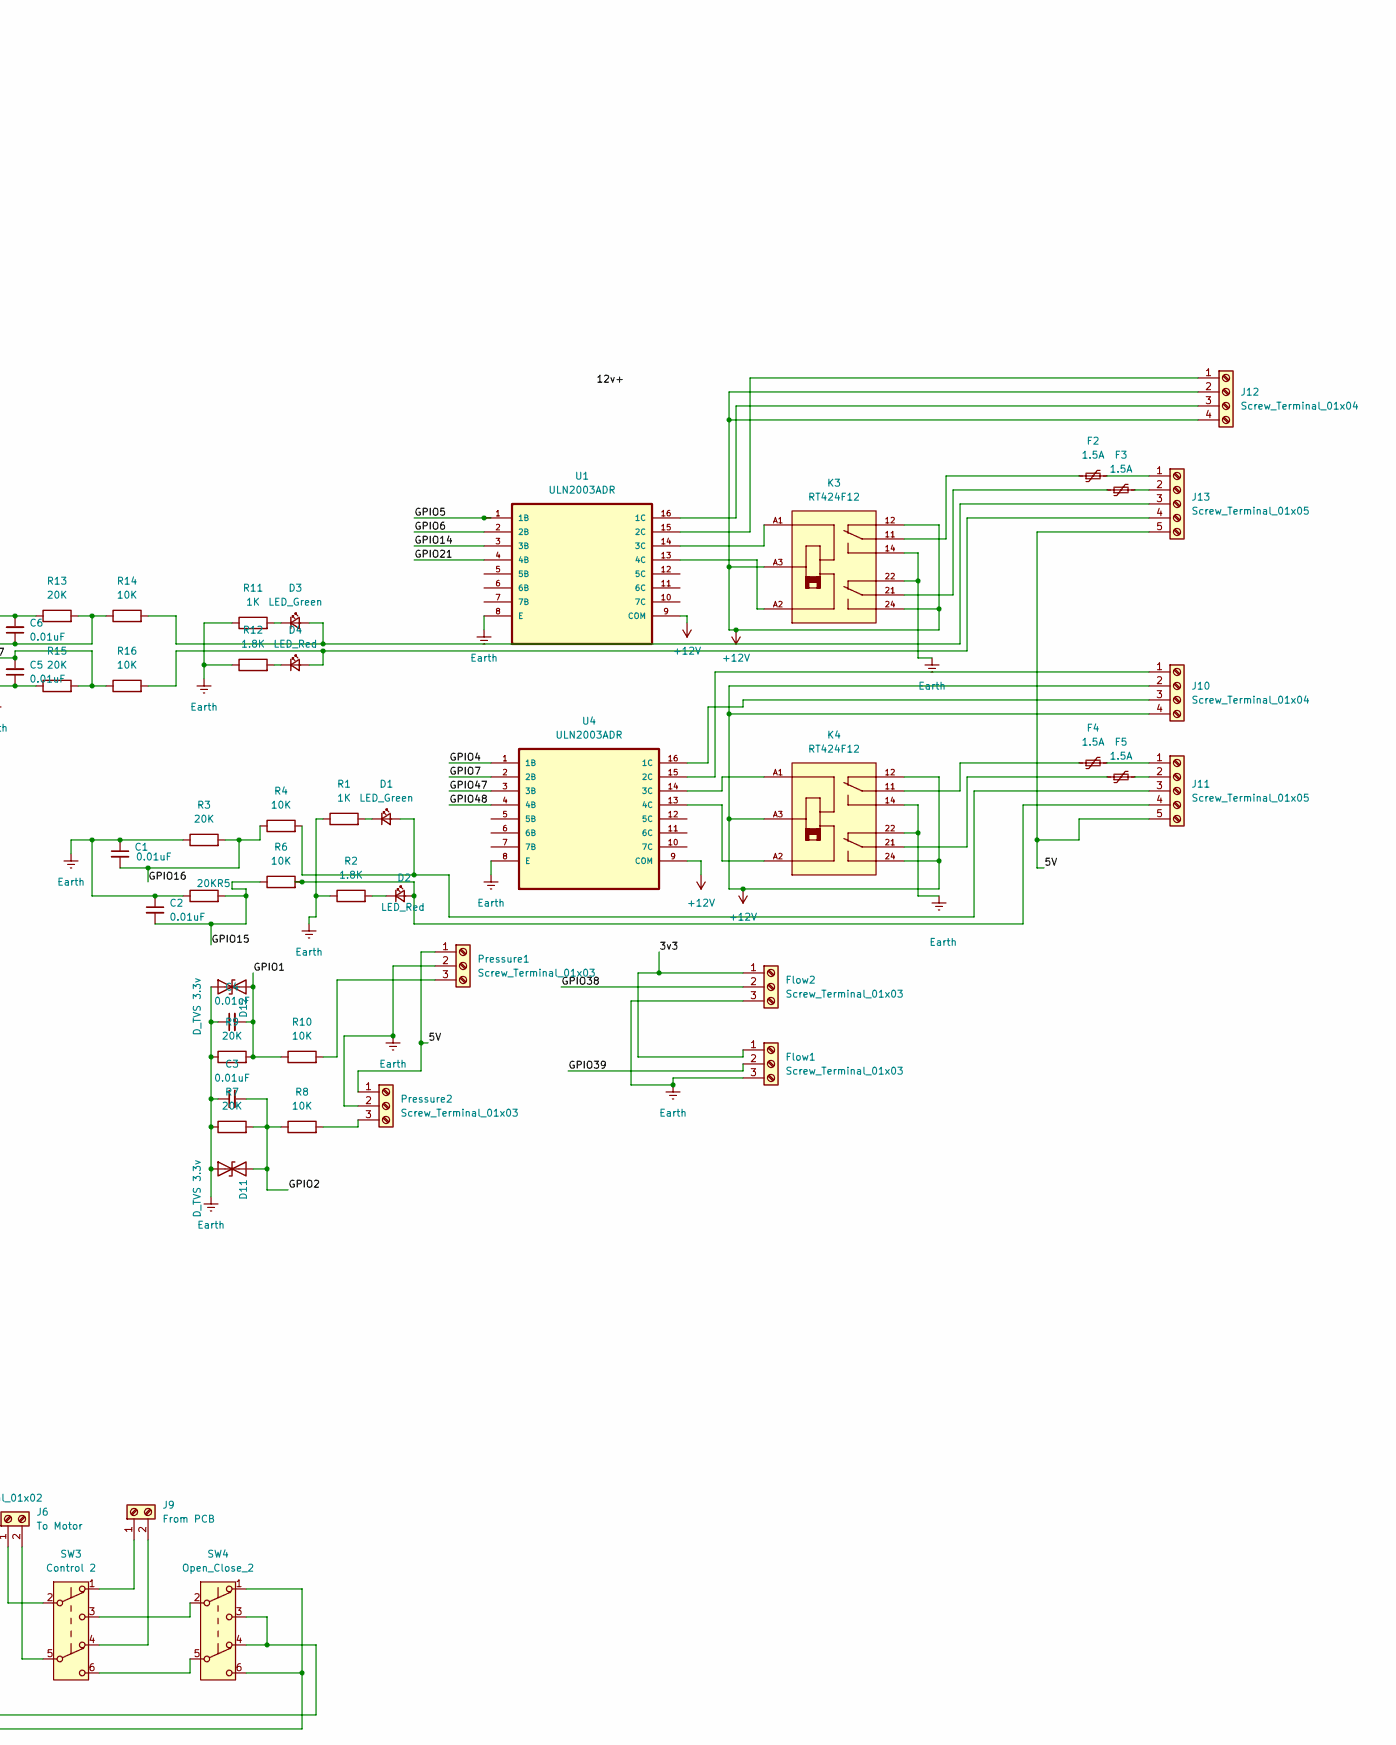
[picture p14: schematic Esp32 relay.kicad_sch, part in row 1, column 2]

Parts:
C1, C2, C3, C4, C5, C6: 0.01uF; C_0603_1608Metric
C7, C8, C11: 10uF; C_0603_1608Metric
C9, C10, C12, C13, C14: 0.1uF; C_0603_1608Metric
D1, D3, D7: LED_Green; LED_0603_1608Metric; Part# B1931NG--20D001114U1930
D2, D4: LED_Red; LED_0603_1608Metric; Part# B1931URO-20D000114U1930
D5, D6: MBR140SFT3G; SOD-123FLv2; Part# MBR140SFT3G
D8, D9, D10: D_TVS; D_SOD-323_HandSoldering
D11, D12: D_TVS 3.3v; D_SOD-323_HandSoldering
F1, F2, F3, F4, F5: 1.5A; Fuse_1812_4532Metric_Pad1.30x3.40mm_HandSolder; Part# 5923-0ZCG0150AF2CCT-ND
Flow1, Flow2: Screw_Terminal_01x03; TerminalBlock_Phoenix_MKDS-1,5-3_1x03_P5.00mm_Horizontal; Part# 1935174
J3, J8: Screw_Terminal_01x02; TerminalBlock_Phoenix_MKDS-1,5-2_1x02_P5.00mm_Horizontal; Part# 1935161
J4: USB_C_Receptacle_USB2.0_16P; USB_C_Receptacle_GCT_USB4105-xx-A_16P_TopMnt_Horizontal
J5, J6: To Motor; TerminalBlock_Phoenix_MKDS-1,5-2_1x02_P5.00mm_Horizontal; Part# 1935161
J7, J9: From PCB; TerminalBlock_Phoenix_MKDS-1,5-2_1x02_P5.00mm_Horizontal; Part# 1935161
J10, J12: Screw_Terminal_01x04; TerminalBlock_Phoenix_MKDS-1,5-4_1x04_P5.00mm_Horizontal; Part# 1935187
J11, J13: Screw_Terminal_01x05; TerminalBlock_Phoenix_MKDS-1,5-5_1x05_P5.00mm_Horizontal; Part# 1935190
J14: GPIO; PinSocket_1x03_P2.54mm_Vertical
J15: SPI; PinSocket_1x04_P2.54mm_Vertical
K3, K4: RT424F12; TE_5-1393243-4; PARTREV 1116
Pressure1, Pressure2: Screw_Terminal_01x03; TerminalBlock_Phoenix_MKDS-1,5-3_1x03_P5.00mm_Horizontal; Part# 1935174
R1, R11, R19: 1K; R_0805_2012Metric; Part# RMCF0805FT1K80CT-ND
R2, R12: 1.8K; R_0805_2012Metric
R3, R5, R7, R9, R13, R15: 20K; R_0805_2012Metric
R4, R6, R8, R10, R14, R16, R20: 10K; R_0805_2012Metric
R17, R18: 5.1K; R_0805_2012Metric
SW1: Control 1; ANT23SECQE DPDT; Part# 100DP3T1B3M2QEH-ND
SW2: Open_Close_1; ANT23SECQE DPDT; Part# 100DP3T1B3M2QEH-ND
SW3: Control 2; ANT23SECQE DPDT; Part# 100DP3T1B3M2QEH-ND
SW4: Open_Close_2; ANT23SECQE DPDT; Part# 100DP3T1B3M2QEH-ND
SW5, SW6: SW_Push; SW PTS636 SP50 SMTR LFS; Part# PTS636 SP50 SMTR LFS
TP1: GND; TestPoint_Pad_1.5x1.5mm; not fitted
TP2: 12V+; TestPoint_Pad_1.5x1.5mm; not fitted
TP3: 5V+; TestPoint_Pad_1.5x1.5mm; not fitted
TP4: 3v3+; TestPoint_Pad_1.5x1.5mm; not fitted
U1, U4: ULN2003ADR; SOIC127P600X175-16N; Part# ULN2003ADR
U2: R-783.3-1.0; Converter_DCDC_RECOM_R-78E-0.5_THT; Part# 945-1036-ND
U3: R-78E5.0-1.0; Converter_DCDC_RECOM_R-78E-0.5_THT; Part# 945-2201-ND
U6: ESP32-S3-WROOM-1; Part# 5407-ESP32-S3-WROOM-1-N8R2CT-ND

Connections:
+12V: C11.1, D5.C, J8.1, J10.2, J10.4, J12.2, J12.4, K3.12, K3.24, K3.A3, K4.12, K4.24, K4.A3, SW2.1 (A), SW2.6 (C), SW4.1 (A), SW4.6 (C), TP2.1 (1_1), U1.9 (COM), U3.1 (IN), U4.9 (COM)
/3v3: C8.1, C10.1, Flow1.1, Flow2.1, R20.2, TP4.1 (1_1), U2.3 (OUT), U6.2 (3V3)
/5V: C7.1, C9.1, D7.2 (A), F1.2, J11.5, J13.5, Pressure1.1, Pressure2.1, TP3.1 (1_1), U2.1 (IN), U3.3 (OUT)
/12VDD: D5.A, J3.1
/CC1: J4.A5 (CC1), R17.1
/CC2: J4.B5 (CC2), R18.1
/CLK: J15.3, U6.20 (IO12)
/CS: J15.1, U6.18 (IO10)
/D+: D10.2 (A2), J4.A6 (D+), J4.B6 (D+), U6.14 (IO20)
/D-: D9.2 (A2), J4.A7 (D-), J4.B7 (D-), U6.13 (IO19)
/EN: C13.1, C14.1, R20.1, SW6.2, U6.3 (EN)
/GPIO0: C12.1, SW5.2, U6.27 (IO0)
/GPIO1: C4.2, D12.2 (A2), R9.2, R10.1, U6.39 (IO1)
/GPIO2: C3.2, D11.2 (A2), R7.2, R8.1, U6.38 (IO2)
/GPIO4: U4.1 (1B), U6.4 (IO4)
/GPIO5: U1.1 (1B), U6.5 (IO5)
/GPIO6: U1.2 (2B), U6.6 (IO6)
/GPIO7: U4.2 (2B), U6.7 (IO7)
/GPIO14: U1.3 (3B), U6.22 (IO14)
/GPIO15: C2.2, R5.2, R6.1, U6.8 (IO15)
/GPIO16: C1.2, R3.2, R4.1, U6.9 (IO16)
/GPIO17: C5.2, R15.2, R16.1, U6.10 (IO17)
/GPIO18: C6.1, R13.2, R14.1, U6.11 (IO18)
/GPIO21: U1.4 (4B), U6.23 (IO21)
/GPIO38: Flow2.2, U6.31 (IO38)
/GPIO39: Flow1.2, U6.32 (IO39)
/GPIO40: J14.1, U6.33 (IO40)
/GPIO41: J14.2, U6.34 (IO41)
/GPIO42: J14.3, U6.35 (IO42)
/GPIO47: U4.3 (3B), U6.24 (IO47)
/GPIO48: U4.4 (4B), U6.25 (IO48)
/MISO: J15.4, U6.21 (IO13)
/MOSI: J15.2, U6.19 (IO11)
Earth: C1.1, C2.1, C3.1, C4.1, C5.1, C6.2, C7.2, C8.2, C9.2, C10.2, C11.2, C12.2, C13.2, C14.2, D8.1 (A1), D9.1 (A1), D10.1 (A1), D11.1 (A1), D12.1 (A1), Flow1.3, Flow2.3, J3.2, J4.A1 (GND), J4.A12 (GND), J4.B1 (GND), J4.B12 (GND), J4.S1 (SHIELD), J8.2, K3.14, K3.22, K4.14, K4.22, Pressure1.2, Pressure2.2, R1.1, R2.1, R3.1, R5.1, R7.1, R9.1, R11.1, R12.1, R13.1, R15.1, R17.2, R18.2, R19.1, SW2.3 (C), SW2.4 (A), SW4.3 (C), SW4.4 (A), SW5.1, SW6.1, TP1.1 (1_1), U1.8 (E), U2.2 (GND), U3.2 (GND), U4.8 (E), U6.1 (GND), U6.40 (GND), U6.41 (GND)
unnamed: D1.2 (A), J11.3, R4.2
unnamed: D1.1 (K), R1.2
unnamed: D2.2 (A), J11.4, R6.2
unnamed: D2.1 (K), R2.2
unnamed: D3.2 (A), J13.3, R14.2
unnamed: D3.1 (K), R11.2
unnamed: D4.2 (A), J13.4, R16.2
unnamed: D4.1 (K), R12.2
unnamed: D6.C, F1.1
unnamed: D7.1 (K), R19.2
unnamed: D6.A, D8.2 (A2), J4.A4 (VBUS), J4.A9 (VBUS), J4.B4 (VBUS), J4.B9 (VBUS)
unnamed: F2.1, K3.11
unnamed: F3.1, K3.21
unnamed: F4.1, K4.11
unnamed: F5.1, K4.21
unnamed: J5.1, SW1.2 (B)
unnamed: J5.2, SW1.5 (B)
unnamed: J6.1, SW3.2 (B)
unnamed: J6.2, SW3.5 (B)
unnamed: J7.1, SW1.1 (A)
unnamed: J7.2, SW1.4 (A)
unnamed: J9.1, SW3.1 (A)
unnamed: J9.2, SW3.4 (A)
unnamed: J10.1, U4.15 (2C)
unnamed: J10.3, U4.16 (1C)
unnamed: F4.2, J11.1
unnamed: F5.2, J11.2
unnamed: J12.1, U1.15 (2C)
unnamed: J12.3, U1.16 (1C)
unnamed: F2.2, J13.1
unnamed: F3.2, J13.2
unnamed: Pressure1.3, R10.2
unnamed: Pressure2.3, R8.2
unnamed: SW1.3 (C), SW2.2 (B)
unnamed: SW1.6 (C), SW2.5 (B)
unnamed: SW3.3 (C), SW4.2 (B)
unnamed: SW3.6 (C), SW4.5 (B)
unnamed: K3.A1, U1.14 (3C)
unnamed: K3.A2, U1.13 (4C)
unnamed: K4.A1, U4.14 (3C)
unnamed: K4.A2, U4.13 (4C)

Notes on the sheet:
8.13

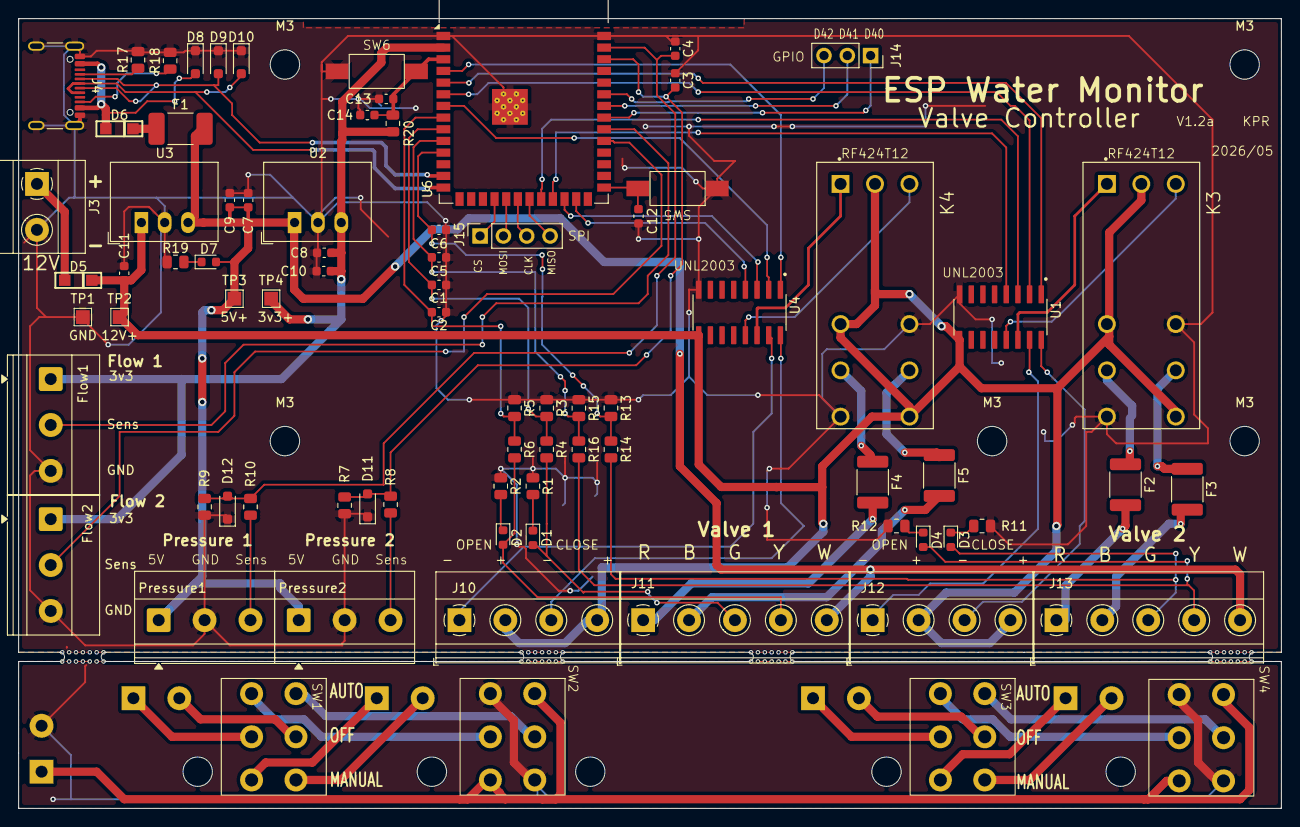
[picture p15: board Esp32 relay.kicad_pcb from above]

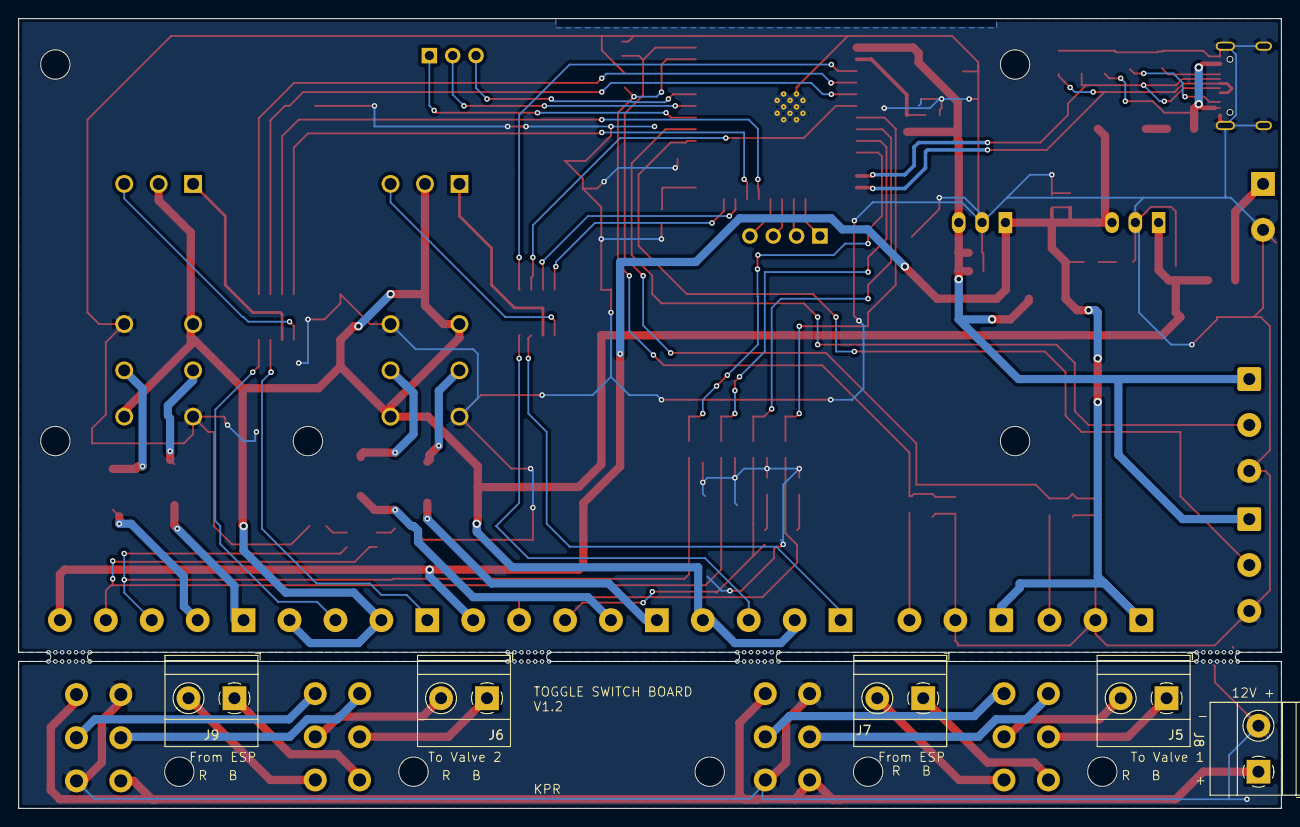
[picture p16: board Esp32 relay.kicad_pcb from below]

Board: 2 copper layers, 137.5 x 86.0 mm, 95 parts (5 on the bottom side), 75 nets.

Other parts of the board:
M3, M3#2, M3#3, M3#4, M3#5, M3#6, M3#7, M3#8, M3#9, M3#10: MountingHole_3.2mm_M3

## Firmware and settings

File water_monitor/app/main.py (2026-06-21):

"""FastAPI entrypoint — boots the orchestrator and serves the web UI."""
from __future__ import annotations

import asyncio
import logging
import re as _re
from contextlib import asynccontextmanager
from pathlib import Path

from fastapi import FastAPI, Request
from fastapi.responses import HTMLResponse
from fastapi.staticfiles import StaticFiles
from fastapi.templating import Jinja2Templates
from jinja2 import select_autoescape

import os as _os

from .config import load_config
from .database import (
    derive_csrf_token,
    get_or_create_csrf_server_secret,
    validate_csrf_token,
)

# Ingress IP guard — only accept requests from the HA supervisor ingress proxy.
# Override via env vars for non-standard deployments and local/pytest runs.
_INGRESS_IP  = _os.environ.get("INGRESS_ALLOWED_IP", "172.30.32.2")
_DEV_MODE    = _os.environ.get("DEV_MODE", "false").lower() in ("true", "1", "yes")

# Session cookie used to bind a browser to its CSRF token via HMAC
# double-submit. Persistent (30 days) and re-set on first response only.
SESSION_COOKIE         = "wm_session"
SESSION_COOKIE_MAX_AGE = 30 * 86400  # 30 days

# Session ids are 64 hex chars (32 bytes). Anything shorter / different
# format means the cookie was tampered with or rotated — treat as new.
SESSION_COOKIE_MIN_LEN = 16


def _new_session_id() -> str:
    import secrets as _s
    return _s.token_hex(32)


def _is_secure_request(request: Request) -> bool:
    """Whether the outer connection (browser -> ingress) was HTTPS.

    HA ingress terminates TLS and the proxied request reaches the addon
    over plain HTTP, so checking ``request.url.scheme`` alone is
    misleading. Trust ``X-Forwarded-Proto`` when present, and default
    to Secure in production (the addon is normally served behind
    ingress over HTTPS). ``DEV_MODE=true`` opts out for local pytest
    runs against plain HTTP loopback.
    """
    if _DEV_MODE:
        return False
    proto = request.headers.get("X-Forwarded-Proto", "").lower()
    if proto in ("https", "http"):
        return proto == "https"
    return True


def _is_health_path(path: str) -> bool:
    """Exact-match /health (with optional trailing slash). Prefix
    `/health-anything` is NOT exempt — that was the old startswith bug.
    """
    return path == "/health" or path == "/health/"


def _is_static_path(path: str) -> bool:
    """/static/foo.css is an asset path. GET-only by design; POST/PUT
    to /static are never legitimate routes."""
    return path.startswith("/static/")


from .db_migrations import run_migrations
from .orchestrator import Orchestrator
from .routers import (dashboard, device, history, fixtures, settings, setup,
                      backup, training, calibration)
from .units import build_unit_context, load_unit_context

APP_DIR = Path(__file__).resolve().parent
log = logging.getLogger(__name__)


def _read_addon_version() -> str:
    """Read the addon `version:` from config.yaml (one line, no YAML dep).

    Used as the static-asset cache-buster so a version bump on deploy busts
    the browser's cached styles.css/JS. Falls back to 'dev' if unreadable.
    """
    try:
        cfg_path = APP_DIR.parent / "config.yaml"
        for line in cfg_path.read_text(encoding="utf-8").splitlines():
            s = line.strip()
            if s.startswith("version:"):
                return s.split(":", 1)[1].strip().strip("\"'") or "dev"
    except Exception:
        pass
    return "dev"


class IngressTemplates(Jinja2Templates):
    """Jinja2Templates that auto-injects ingress_path, CSRF token, and
    unit context into every template response.

    CSRF token comes from ``request.state.csrf_token`` which the
    middleware computes once per request from the browser's session_id
    cookie + the persisted server secret. No DB writes per render and
    no shared process-wide cache.
    """

    def TemplateResponse(self, name, context, **kwargs):
        request = context.get("request")
        orch_ref = None
        if request:
            context.setdefault(
                "ingress_path",
                getattr(request.state, "ingress_path", "")
            )
            orch_ref = getattr(request.app.state, "orchestrator", None)
            context.setdefault(
                "csrf_token",
                getattr(request.state, "csrf_token", ""),
            )
            # Static-asset cache-buster (see _read_addon_version). Defaults to
            # 'dev' before lifespan sets it / outside the app context.
            context.setdefault(
                "asset_version",
                getattr(request.app.state, "asset_version", "dev"),
            )
            # Hide the top-level Setup tab once initial setup is complete;
            # the wizard is locked anyway, so the tab would be a dead-end.
            # Re-runs go through Settings -> Re-run Setup, which flips this
            # back to 0 and the tab reappears.
            context.setdefault(
                "setup_complete",
                bool(getattr(orch_ref, "setup_complete", False)),
            )
        # Inject unit conversion context so every template and the JS
        # window.UNITS global have the correct factors and labels.
        if orch_ref and orch_ref.db:
            uc = load_unit_context(orch_ref.db)
            for k, v in uc.items():
                context.setdefault(k, v)
        else:
            # Fallback defaults before DB is ready
            for k, v in build_unit_context("L/min", "psi").items():
                context.setdefault(k, v)
        return super().TemplateResponse(name, context, **kwargs)


@asynccontextmanager
async def lifespan(app: FastAPI):
    cfg = load_config()
    log_level = getattr(logging, cfg.log_level.upper(), logging.INFO)
    logging.basicConfig(
        level=log_level,
        format="%(asctime)s %(levelname)s %(name)s: %(message)s",
    )
    # Suppress noisy third-party loggers regardless of app log level
    logging.getLogger("websockets").setLevel(logging.WARNING)
    logging.getLogger("websockets.client").setLevel(logging.WARNING)
    logging.getLogger("websockets.server").setLevel(logging.WARNING)
    logging.getLogger("uvicorn.access").setLevel(logging.WARNING)
    logging.getLogger("uvicorn.error").setLevel(logging.WARNING)
    logging.getLogger("multipart").setLevel(logging.WARNING)
    logging.getLogger("multipart.multipart").setLevel(logging.WARNING)
    log = logging.getLogger(__name__)
    log.info("Water Monitor starting — %d circuits configured",
             len(cfg.circuits))

    orch = Orchestrator(cfg)
    app.state.orchestrator = orch

    # Initialise DB and run migrations before the orchestrator's async run()
    # so the schema is fully up to date before any component starts.
    # Close the connection immediately after — orchestrator.run() opens its
    # own connection (self._db) which is the one used by all components.
    # Leaving this first connection open leaks a SQLite handle and holds
    # a shared lock that can interfere with WAL checkpointing.
    from .database import init_db
    from .config import DB_PATH
    _db = init_db(DB_PATH)
    try:
        run_migrations(_db, db_path=DB_PATH)
        # Cache the CSRF HMAC secret on app.state so the middleware
        # doesn't hit the DB on every request. The orchestrator's own
        # connection will be used for any post-startup reads.
        app.state.csrf_server_secret = get_or_create_csrf_server_secret(_db)
    except Exception as e:
        log.critical("DB migration failed — cannot start: %s", e)
        raise
    finally:
        _db.close()

    # autoescape pinned explicitly. Starlette's Jinja2Templates default
    # has been select_autoescape(["html", "htm"]) for a long time, but
    # the safety belt is cheap and survives any future framework
    # default change. Every {{ … }} in our .html templates is escaped
    # by default; |safe is required to opt out.
    app.state.templates = IngressTemplates(
        directory=str(APP_DIR / "templates"),
        autoescape=select_autoescape(["html", "htm"]),
    )

    # Static-asset cache-buster — derived from the addon version so a deploy
    # version bump automatically busts the browser's cached styles.css / JS.
    app.state.asset_version = _read_addon_version()

    # Register tojson filter (not included by default in FastAPI's Jinja2).
    # Must return Markup so Jinja2 autoescape does not HTML-encode the JSON
    # (which would turn & -> &amp; and break JavaScript parsing).
    import json as _json
    from markupsafe import Markup as _Markup
    app.state.templates.env.filters["tojson"] = (
        lambda v: _Markup(_json.dumps(v))
    )

    # fixture_icon: maps a cluster dict to an emoji for the fixture type.
    _FX_ICONS = {
        "toilet":          "\U0001F6BD",  # 🚽
        "shower_tub":      "\U0001F6BF",  # 🚿
        "tap":             "\U0001F6B0",  # 🚰
        "washing_machine": "\U0001F455",  # 👕
        "dishwasher":      "\U0001F37D",  # 🍽
        "irrigation_zone": "\U0001F4A7",  # 💧
        "other":           "❓",
        "leak_test":       "\U0001F50D",  # 🔍
    }
    app.state.templates.env.filters["fixture_icon"] = (
        lambda cl: _FX_ICONS.get(
            (cl.get("user_type") or cl.get("suggested_type") or "other"),
            "❓"
        )
    )

    runner = asyncio.create_task(orch.run())

    try:
        yield
    finally:
        log.info("Water Monitor shutting down")
        orch.stop()
        runner.cancel()
        try:
            await runner
        except (asyncio.CancelledError, Exception):
            pass


app = FastAPI(
    lifespan=lifespan,
    title="Water Monitor",
    redirect_slashes=False,  # prevent /setup -> /setup/ redirects that break ingress
)

app.mount(
    "/static",
    StaticFiles(directory=str(APP_DIR / "static")),
    name="static",
)


@app.middleware("http")
async def ingress_middleware(request: Request, call_next):
    # Store ingress path from HA proxy header for use in templates
    ingress_path = request.headers.get("X-Ingress-Path", "").rstrip("/")
    request.state.ingress_path = ingress_path

    path = request.url.path

    # Reject requests that did not arrive through the HA ingress proxy.
    # /health (exact) is exempt so Docker and HA health probes (which
    # come directly, not through ingress) continue to work. The previous
    # startswith check also exempted /health-anything — that's fixed
    # here by using an exact-match.
    # Disabled when DEV_MODE=true or INGRESS_ALLOWED_IP="" for local
    # dev/tests.
    if (not _DEV_MODE and _INGRESS_IP
            and not _is_health_path(path)):
        client_ip = request.client.host if request.client else ""
        if client_ip != _INGRESS_IP:
            log.warning("Rejected request from non-ingress IP %s on %s",
                        client_ip, path)
            from fastapi.responses import Response as _Resp
            return _Resp(status_code=403, content=b"Forbidden")

    # Log every POST so we can see what's reaching the addon
    if request.method == "POST":
        log.info("POST %s (ingress=%r)", path, ingress_path)

    # ----- Session + CSRF token derivation ---------------------------
    # Stateless HMAC double-submit (see plan A-1):
    #   - browser carries a random session_id in a cookie
    #   - server caches the persistent HMAC secret on app.state
    #   - csrf_token = HMAC(server_secret, session_id)
    # No DB write per request; no shared process-wide cache.
    orch = getattr(request.app.state, "orchestrator", None)
    server_secret: str = getattr(
        request.app.state, "csrf_server_secret", ""
    )
    if not server_secret and orch and getattr(orch, "db", None):
        server_secret = get_or_create_csrf_server_secret(orch.db)
        request.app.state.csrf_server_secret = server_secret

    session_id = request.cookies.get(SESSION_COOKIE, "")
    new_session = False
    if not session_id or len(session_id) < SESSION_COOKIE_MIN_LEN:
        session_id = _new_session_id()
        new_session = True
    request.state.session_id = session_id
    request.state.csrf_token = (
        derive_csrf_token(server_secret, session_id)
        if server_secret else ""
    )

    # ----- CSRF validation -------------------------------------------
    # Only state-changing methods need a token. Exempt:
    #   - exact /health  (probes — no token possible)
    #   - /static/*      (asset paths — POSTs are illegitimate)
    # Setup-wizard POSTs are NO LONGER exempt — the first GET sets the
    # session cookie and provides the token.
    if request.method in ("POST", "PUT", "PATCH", "DELETE") and not (
            _is_health_path(path) or _is_static_path(path)):
        # 1. Header first (covers JSON, no-body, and all fetch POSTs)
        token = request.headers.get("X-CSRF-Token", "")
        # 2. Fall back to form/multipart body
        if not token:
            ct = request.headers.get("Content-Type", "")
            if ("application/x-www-form-urlencoded" in ct
                    or "multipart/form-data" in ct):
                # Drain the body once, replay it for downstream handlers
                body_bytes = await request.body()

                async def receive_replay():
                    return {
                        "type": "http.request",
                        "body": body_bytes,
                        "more_body": False,
                    }
                request._receive = receive_replay

                form_data = await request.form()
                token = form_data.get("_csrf", "")

                # Clear Starlette's form cache so the route handler
                # re-parses from the replayed body
                if hasattr(request, "_form"):
                    request._form = None

        if not validate_csrf_token(server_secret, session_id, token):
            log.warning("CSRF invalid on %s %s", request.method, path)
            return HTMLResponse(
                "<h1>403 — Invalid or missing security token</h1>"
                "<p>Please reload the page and try again.</p>",
                status_code=403,
            )

    # ----- Setup-complete redirect -----------------------------------
    # First-run users get bounced to the setup wizard until it's done.
    # The redirect-skip set still uses startswith for /setup so wizard
    # sub-paths don't bounce-redirect into themselves; /health is now
    # exact-match.
    skip_redirect = (
        path.startswith("/setup")
        or _is_static_path(path)
        or _is_health_path(path)
    )
    if not skip_redirect:
        if orch and not orch.setup_complete:
            # Sanitise the HA-supplied ingress path before embedding in HTML.
            # Allow only URL-safe path characters; strip anything else to
            # prevent header-injection attacks.
            ingress_path = _re.sub(r"[^/a-zA-Z0-9_\-]", "", ingress_path)
            setup_url = f"{ingress_path}/setup"
            return HTMLResponse(
                content=(
                    f"<!doctype html><html><head>"
                    f'<meta http-equiv="refresh" content="0; url={setup_url}">'
                    f"</head><body>"
                    f'<script>window.location.replace("{setup_url}");</script>'
                    f"Redirecting to setup…"
                    f"</body></html>"
                ),
                status_code=200,
            )

    response = await call_next(request)

    # Set the session cookie on the response if this was a new browser.
    # Attach it to every response shape (template, redirect, JSON, 4xx)
    # so the next request always carries it.
    if new_session:
        response.set_cookie(
            SESSION_COOKIE,
            session_id,
            httponly=True,
            samesite="lax",
            secure=_is_secure_request(request),
            max_age=SESSION_COOKIE_MAX_AGE,
            path="/",
        )
    return response


# Defense-in-depth response headers (plan C-IQ-18). Applied to every
# response on top of the per-route content. Behind HA ingress these
# mostly guard against accidental drift (a future template that loads
# a third-party script, a same-host XSS proxying through us); they
# also harden the addon if a user ever exposes it directly.
#
# CSP is deliberately permissive: the current UI has ~60 inline event
# handlers (onclick="…") and a few inline <script> / <style> blocks,
# plus Chart.js loaded from cdnjs. A strict CSP would require
# refactoring all of those to external files + per-request nonces.
# What we ship today catches the easy wins (frame-ancestors,
# object-src, base-uri) and pins the CDN origin so a compromised
# template can't pull script from anywhere new. Future tightening
# (drop 'unsafe-inline' for script-src, self-host Chart.js) is its
# own sprint.
_CHART_CDN = "https://cdnjs.cloudflare.com"
_CSP_DIRECTIVES = (
    "default-src 'self'; "
    f"script-src 'self' 'unsafe-inline' {_CHART_CDN}; "
    "style-src 'self' 'unsafe-inline'; "
    "img-src 'self' data:; "
    "font-src 'self' data:; "
    "connect-src 'self'; "
    "frame-ancestors 'self'; "
    "form-action 'self'; "
    "base-uri 'self'; "
    "object-src 'none'"
)


@app.middleware("http")
async def security_headers_middleware(request: Request, call_next):
    """Set defense-in-depth response headers on every response.

    Skipping `/static/*` would also be defensible, but static assets
    serving CSS/JS benefit from `X-Content-Type-Options: nosniff` too,
    so headers are applied uniformly. `/health` keeps the headers
    since they don't break a JSON response.
    """
    response = await call_next(request)
    # X-Frame-Options: SAMEORIGIN keeps HA ingress (which iframes the
    # addon inside the HA dashboard) working while blocking cross-origin
    # embedding. `frame-ancestors 'self'` in the CSP gives the same
    # guarantee for modern browsers; XFO stays as belt-and-suspenders
    # for older clients.
    response.headers.setdefault("X-Frame-Options", "SAMEORIGIN")
    response.headers.setdefault("X-Content-Type-Options", "nosniff")
    response.headers.setdefault("Referrer-Policy", "same-origin")
    response.headers.setdefault("Content-Security-Policy", _CSP_DIRECTIVES)
    return response


app.include_router(setup.router)
app.include_router(dashboard.router)
app.include_router(device.router)
app.include_router(history.router)
app.include_router(fixtures.router)
app.include_router(settings.router)
app.include_router(backup.router)
app.include_router(training.router)
app.include_router(calibration.router)


@app.get("/health")
async def health():
    return {"status": "ok"}

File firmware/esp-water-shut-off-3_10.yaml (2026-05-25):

# =============================================================================
# ESP Smart Water Shut-Off Controller
# Device: ESP32-S3-DevKitC-1
# Controls two motorized ball valves:
#   Valve 1 — Main water supply shutoff
#   Valve 2 — Irrigation supply shutoff
#
# Each valve is driven by a gear motor with a built-in motor controller that
# cuts power automatically when the valve reaches end of travel. Direction is
# set by dual-coil latching relays — one coil latches the relay OPEN (drives
# motor to open position), the other latches it CLOSED (drives motor to close).
# The relay holds its position mechanically with no power after latching.
#
# Physical end stop switches confirm when each valve has fully opened or closed.
# These are used to:
#   - Update valve state in Home Assistant
#   - Drive the open/closed indicator LEDs on the control panel
#   - Detect motor/wiring faults if travel takes longer than expected
#
# Safety features:
#   - High flow rate shutoff (possible burst pipe)
#   - Rapid pressure drop shutoff (possible pipe break)
#   - Leak test mode (monitors pressure decay with valves closed)
#   - Sustained low flow alert (running toilet, dripping faucet, tap left on)
#   - End stop timeout fault (motor or wiring fault detection)
#   - All safety faults require manual reset — no auto-recovery
#   - Valves operate independently; a fault on one does not affect the other
#
# Bypass switches on the control board allow manual valve operation without
# the ESP32. On power-up or return from bypass, the ESP reads the end stops
# and immediately restores the correct valve state in Home Assistant.
#
# Water signature sensors:
#   pressure_main_base / pressure_irrigation_base (internal)
#     Single ADC sensor per pressure GPIO pin. Performs calibration and
#     clamping only. All derived sensors are copy platform sensors.
#   pressure_main / pressure_irrigation
#     Copy of base sensor, 1.375s window (275 samples), 2Hz to HA.
#     Normal entity (recorded by HA recorder). Used for historical event
#     import and anomaly detection. 1.375s smoothing preserves transient
#     shape with minimal distortion.
#   pressure_main_fast / pressure_irrigation_fast
#     Copy of base sensor, 50ms window (10 samples), 40Hz to HA.
#     entity_category: diagnostic (not recorded). Used by the add-on for
#     live pressure transient detection and resistance curve computation.
#   flow_pulse_onset_main / flow_pulse_onset_irr
#     Template binary sensors derived from the raw base pulse counters
#     (flow_base_main / flow_base_irr). Transition ON when any pulse
#     arrives in the 1s window, delayed_off: 8s prevents fragmentation.
#     ~1s onset latency (ESPHome 2026.4+ prevents GPIO pin sharing).
# =============================================================================

substitutions:
  flow_k_factor: "396.0"   # 6.6 pulses/litre × 60s = 396
  circuit_1_name: "Main"        # Display name for circuit 1 — change to suit your install
  circuit_2_name: "Irrigation"  # Display name for circuit 2 — change to suit your install

esphome:
  name: esp-water-shut-off-3
  friendly_name: ESP Water Shut off 3.10
  min_version: 2024.6.0
  name_add_mac_suffix: false
  platformio_options:
    # DIO flash mode required for ESP32-S3
    board_build.flash_mode: dio
  project:
    name: ronan.esp-water-monitor
    version: "3.10.0"

  # ---------------------------------------------------------------------------
  # BOOT SEQUENCE
  # Runs once after all components have initialised (priority -100 ensures
  # sensors and binary_sensors are ready before this executes).
  #
  # Purpose: If the ESP has just powered on, or the bypass switch has returned
  # the valves to ESP "auto" control, the end stops reflect the true physical
  # valve positions. We read them here and publish the correct state to Home
  # Assistant so the dashboard is accurate immediately without needing to
  # move either valve first.
  # ---------------------------------------------------------------------------
  on_boot:
    priority: -100
    then:
      # --- Valve 1 (Main) ---
      # If the open end stop is active, valve is fully open
      - if:
          condition:
            binary_sensor.is_on: open_end_stop_valve1
          then:
            - output.turn_on: led_open_valve1
            - output.turn_off: led_closed_valve1
            - valve.template.publish:
                id: main_water_valve
                state: OPEN
      # If the closed end stop is active, valve is fully closed
      - if:
          condition:
            binary_sensor.is_on: closed_end_stop_valve1
          then:
            - output.turn_on: led_closed_valve1
            - output.turn_off: led_open_valve1
            - valve.template.publish:
                id: main_water_valve
                state: CLOSED
      # Note: if neither end stop is active on boot, state stays unknown
      # in HA until the next valve movement completes.
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

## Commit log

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2026-05-04 Fix CSRF middleware consuming form body before handlers can read it
    BaseHTTPMiddleware (Starlette) consumes the request body when it
    parses the form. The downstream handler's await request.form() then
    returned empty, causing every CSRF-validated POST to silently lose
    its form data — even though CSRF validation itself passed.
    Fix by reading the body once, replaying it through request._receive,
    and clearing the cached form so the handler re-parses the preserved
    body. Affects all 8 forms protected by the CSRF middleware.
    Diagnostic logging on the away-mode toggle removed.
    [main.py]
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2026-05-04 Daily leak test schedule + narrow-card UI fixes
    - Add 'daily' frequency option with corresponding scheduler branch
    (today at run time, or tomorrow if already past).
    - Hide Day picker when frequency is daily — irrelevant.
    - Replace .form-row layout (160px label + field) with .schedule-row
    (stacked, full-width). The original layout was designed for the
    Settings page; in the narrow Device card it left dropdowns and
    number inputs cramped.
    - Inline layout for checkbox rows so they stay compact.
    [leak_test_scheduler.py]
2026-05-04 leak test auto/manual toggle + dead-column cleanup
    v0.2.0-dev cleanup: leak test auto/manual toggle + dead-column cleanup
    - Add Auto-pick quiet hour toggle on the leak test schedule (default
    ON, matches previous behaviour). When OFF, the scheduler respects
    the user's run_hour/run_minute instead of overriding it from usage
    history.
    - Migration 014 drops two unused columns (home_profile.away_until,
    leak_test_schedule.custom_interval_days) and adds auto_learn_hour.
    - Remove dead `custom` frequency branch from the scheduler.
    Audited remaining db columns and form fields against UI exposure;
    two suspected disconnects (history date filters, setup device fields)
    turned out to be false posi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
    [database.py, db_migrations.py, leak_test_scheduler.py]
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2026-05-05 Fix duplicate events: deterministic IDs + dedup migration
    - feature_extractor: derive event ID from uuid5(circuit/start_ts)
    instead of uuid4(); re-processing the same event now upserts
    rather than inserting a duplicate row
    - db_migrations 015: one-shot cleanup of pre-existing duplicates,
    keeping the earliest rowid per (circuit, start_ts)
    [db_migrations.py, feature_extractor.py]
2026-05-05 Phase 2: fixture detection, clustering engine, and fixtures UI
    - clusterer.py: DBSCAN on event features; populates fixture_clusters,
    writes cluster_id back to events, builds cooccurrence table
    - training_manager: trigger clustering on calibration end; add
    retrigger_clustering() for manual re-runs from fixtures page
    - fixtures router: confirm/override/delete cluster labels, re-run
    clustering, JSON API
    - fixtures.html: cluster card grid with stats, confirm form, review
    banner, calibrating/empty states
    - Bug fix: device entity values (flow/pressure thresholds) now shown
    and saved in user's chosen display units
    - Migration 016: fixture lookup indexes
    [database.py, db_migrations.py, fixtures.py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]
2026-05-05 Phase 2.1 Stage 2: core DBSTREAM clustering engine
    - New cluster_engine.py: per-circuit DBSTREAM + StandardScaler,
    match_and_learn per-event, rebuild_from_db on startup with
    centroid-matching ID map recovery after restart
    - feature_extractor.py: sequence context (seconds_since_prev,
    prev_cluster_id) + cluster matching wired after each event write
    - orchestrator.py: instantiate ClusterEngine, rebuild state per
    circuit, wire to feature extractor
    - Remove clusterer.py (batch DBSCAN, rejected per ADR 003)
    - training_manager.py: remove DBSCAN clustering calls
    - routers/fixtures.py: retrigger endpoint calls rebuild_from_db
    - CLAUDE.md: update migration count and stage status
    [cluster_engine.py, feature_extractor.py, fixtures.py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]
2026-05-05 Phase 2.1 gap fixes: clustering correctness, MQTT publishing, metrics, history badges
    Major gaps closed
    - Gap 1: Add ClusterEngine.backfill_unmatched() to retroactively assign cluster_id to
    events collected before DBSTREAM was deployed (v0.1.x upgrade path). Called from
    orchestrator after rebuild_from_db and from training_manager.complete_calibration.
    - Gap 2: Wire cooccurrence write path — _update_cooccurrence() records cluster
    transitions with running-mean gap_seconds. match_and_learn now accepts
    prev_cluster_id/seconds_since_prev and writes to cluster_cooccurrence table.
    Stage 3 sequence-boost reads from this table.
    - Gap 3: DTW stub comment block documents Stage 3 dtaidistanc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
    [cluster_engine.py, cluster_metrics.py, data_pruner.py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]
2026-05-05 Fix three bugs found in code review
    - history.html: shape pill mapped 'flat' instead of 'steady' — feature_extractor
    always emits 'steady', so the blue pill never appeared for steady-state events
    - cluster_engine: centroid running mean used new sample value as missing-key
    default instead of 0.0, causing old observations to contribute nothing for
    absent keys
    - data_pruner: fixture_daily_summary.day is DATE not TIMESTAMP — use date(?) in
    WHERE clause to avoid string-comparison edge case where 'YYYY-MM-DD' compares
    less than 'YYYY-MM-DDT00:00:00+00:00', incorrectly deleting the cutoff-day row
    [cluster_engine.py, data_pruner.py]
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2026-05-05 Preserve calibration timer when wizard re-runs after restore
    After a backup restore, the setup wizard reappears (intentionally — for device re-verification) and its final step calls start_calibration() for every circuit. The old implementation accepted both idle and calibrating as legal start states and unconditionally reset started_at = now and events_collected = 0, wiping any restored progress (a 3-day-old backup showed 13d 23h remaining instead of ~11d).
    start_calibration() now short-circuits when the circuit is already calibrating with a valid started_at, preserving the timer and event counter. Both legitimate restart paths (trigger_full_recalibration and settings.py's occupants-chang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
    [training_manager.py]
2026-05-09 Add per-fixture-type variance profiles + match thresholds
    Introduces FIXTURE_VARIANCE_PROFILES and FIXTURE_MATCH_THRESHOLDS in fixtures.py — one entry per fixture type. Profiles describe which features should be anchored (high weight), which should be ignored as user behaviour (zero weight), expected coefficient-of-variation for future drift detection, and a multimodal flag for the deferred Phase 2.2 multi-cluster grouping. Thresholds are tuned categorically: tight for deterministic fixtures (toilet 0.6, ice maker 0.5), loose for user-driven (shower 2.5, taps 1.8) and multimodal (washing machine 3.0). Pure data + helpers — no behaviour change. cluster_engine consumes these in the next co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
    [fixtures.py]
2026-05-09 Phase 2.1: type-aware match gate in cluster_engine
    Phase 2.1: type-aware match gate in cluster_engine
    Confirmed fixtures now use per-type weighted-distance + match
    threshold instead of the uniform DBSTREAM threshold. Toilets and
    ice makers reject out-of-spec volumes; showers and taps tolerate
    variable durations. Unconfirmed clusters keep the existing
    discovery behaviour.
    - _type_cache populated at startup from confirmed fixtures, mutated
    live by notify_fixture_confirmed/removed (no restart needed)
    - weighted distance amplifies anchor features, zeroes float features
    - gate rejection records 'type_gate_rejected' in events.match_rejection_reason
    alongside 'features_missing' / 'no_centers' f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
    [cluster_engine.py, database.py, feature_extractor.py]
2026-05-09 Phase 2.1: wire notify hooks into fixtures router
    After confirming or deleting a cluster, the cluster engine's type
    cache is updated live. No restart needed for gate changes to take
    effect.
    [fixtures.py]
2026-05-09 Phase 2.1: tests + CHANGELOG for type-aware match gate
    17 unit tests covering weighted distance, type cache lifecycle,
    toilet gate rejection, shower float-feature acceptance, schema
    drift guard, multi-circuit isolation, and fail-open behaviour.
    Also fixes fixture_clusters.centroid NOT NULL with DEFAULT '{}'.
    [database.py]
2026-05-09 Phase 2.1: plumbing-event exclusion windows
    Phase 2.1: plumbing-event exclusion windows
    User-triggered exclusion windows prevent post-winterization or
    post-repair flush events from polluting fixture training. Volume
    tracking continues regardless. Settings → per-circuit card to
    start (5–60 min), cancel, or extend +15 min. Fixtures page
    shows active status. Pruned after 30 days.
    [data_pruner.py, database.py, feature_extractor.py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]
2026-05-09 Fix bugs found in post-implementation review of Phase 2.1
    - cluster_engine: _upsert_cluster INSERT now sets centroid='{}' and
    feature_std='{}' explicitly. Previously relied on the schema DEFAULT,
    which fails on existing installs whose fixture_clusters table was
    created before the DEFAULT was added (NOT NULL constraint error on
    every new micro-cluster).
    - database: create_exclusion_window now closes any existing active
    window for the circuit before opening a new one, so double-clicking
    "Mark plumbing event" can't accumulate overlapping rows.
    - test_cluster_engine: replace vacuous "irrigation" not in
    _type_cache["main"].values() check with a real equality + identity
    assertion.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
    [cluster_engine.py, database.py]
2026-05-09 Add labelling state + clean-start guarantee for calibration
    Reintroduce the labelling state from the original training-manager design (deferred in Phase 1, now needed in Phase 2.1). Calibration now ends in a review window where the user confirms detected clusters before the circuit goes live, rather than auto-promoting to live and silently running anomaly detection against unconfirmed clusters.
    complete_calibration transitions calibrating → labelling (was → live)
    New activate_fixtures(circuit) method: labelling → live, called from new POST /fixtures/{circuit}/activate endpoint
    _check_progress auto-activates after 7 days of no review so circuits aren't stuck
    start_calibration now allow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
    [cluster_engine.py, fixtures.py, training_manager.py]
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2026-05-09 fix: BUG-01 through BUG-08 — codebase audit fixes
    BUG-01: leak_test_scheduler — dir() guard always True + missing column KeyError
    BUG-02: event_detector — silent event loss on full queue (put_nowait + warning)
    BUG-03: presence_watcher — all([]) false away-mode at startup
    BUG-04: routers/backup — partial restore wipes DB (wrap in transaction)
    BUG-05: fixture_publisher — SQLite accessed from paho thread (call_soon_threadsafe)
    BUG-06: feature_extractor — hour_ts format inconsistency (+00:00 vs no suffix)
    BUG-07: routers/settings — prune_now() blocks event loop (run_in_executor)
    BUG-08: routers/setup — no file size limit + unatomic restore + missing dedup
    Also fixes migration 0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
    [database.py, db_migrations.py, event_detector.py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]
2026-05-09 fix: BUG-09 through BUG-20 + SUSP-02/06/07/09 — codebase audit round 2
    fix: BUG-09 through BUG-20 + SUSP-02/06/07/09 — codebase audit round 2
    BUG-09: _get_sensitivity: 0.0 thresholds reverted to preset (or → is not None)
    BUG-12: event_detector: pressure skip for zero-baseline (is not None)
    BUG-13: main: leaked DB connection after migrations (close in finally)
    BUG-14: data_pruner: stale summaries never recomputed (date() wrapping)
    BUG-15: ha_client: unbounded ws.recv() loops (wait_for with timeout)
    BUG-16: historical_importer: queue.put() hangs on full queue (put_nowait)
    BUG-17: feature_extractor: anomaly_score never set (dead alert branch fixed)
    BUG-19: training_manager: stale fixture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
    [data_pruner.py, database.py, device_discovery.py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]
2026-05-09 fix: SUSP-02 hotfix — update_home_profile allowlist crashes
    setup wizard
    Static _HOME_PROFILE_COLUMNS frozenset was missing setup_complete,
    publish_fixtures_to_ha, mobile_notify_targets, and mqtt_publish_enabled,
    causing a ValueError crash on POST /setup/home.
    Replaced the hardcoded list with a live PRAGMA table_info(home_profile)
    query so the allowlist is always in sync with the schema — future
    migrations that add columns are automatically permitted without needing
    a corresponding change here.
    [database.py]
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2026-05-09 fix: make event_detector.setup() idempotent + activate after wizard
    Two related fixes for the "monitoring 0 entities" gap on first-run:
    1. routers/setup.py — POST /setup/home now calls event_detector.setup(),
    _init_volume_baselines(), and presence_watcher.sync_initial_state()
    after wizard completion so the first day of monitoring is not lost
    on a fresh install (previously required a manual restart).
    2. event_detector.py — setup() is now idempotent via an _is_configured
    flag. Without this guard, re-running the setup wizard on an already-
    working system (e.g. restore + re-wizard) would register duplicate
    HA subscriptions, causing every state-change to be processed twice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
    [event_detector.py]
2026-05-09 fix: clamp implausible flow rate values to 0.0 (ESP ADC overflow)
    The ESP firmware occasionally emits ~1.58e36 L/min (float overflow /
    ADC error). This was stored directly in _current_flow_lpm, causing the
    event end condition (flow_rate < 0.05) to be permanently false — events
    were stuck open in memory forever with no log output.
    Added MAX_FLOW_LPM = 1000.0 constant. on_flow_rate() now clamps any
    reading above MAX_FLOW_LPM or below 0.0 to 0.0 and emits a WARNING,
    making the end condition behave correctly when the sensor faults.
    [event_detector.py]
2026-05-09 fix: clamp flow sensor ADC garbage values in firmware v3.5 and addon
    ESPHome can emit implausible flow rate values from ADC errors in two directions:
    Underflow noise — tiny positive near-zero values (e.g. 1.58e-36 L/min) from floating-point noise when the pulse counter sees zero pulses. Technically positive so the old x < 0.0 / raw_flow < 0.0 guards missed them entirely.
    Overflow saturation — very large values (e.g. 1.58e+36 L/min) from ADC saturation. Caught by the upper bound guards added previously.
    Firmware v3.5 (esp-water-shut-off-3_5.yaml): adds a guard lambda between the L/min conversion step and the 30-sample sliding window on both water_usage1 (main) and water_usage2 (irrigatio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
    [esp-water-shut-off-3_5.yaml, event_detector.py]
2026-05-09 firmware and addon bug fixes + importer improvements
    Addresses all findings from the code review of firmware v3.5 and the HA addon.
    Bugs fixed
    ----------
    - feature_extractor: pressure readings (40 Hz) were index-paired with flow
    readings (1 Hz) in _classify_resistance_shape, matching the first ~0.75 s of
    pressure against the full event duration. Now bin-averaged to match flow rate
    before the shape classifier runs.
    - historical_importer: pre-v3.5 HA history contains unclamped ADC garbage
    values (e.g. 1.58e+36 L/min) that bypassed the max(flow) guard. Added
    _clamp_flow / _clamp_pressure helpers matching firmware v3.5 bounds and
    applied them to all three reading lists in _reconstr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
    [esp-water-shut-off-3_5.yaml, event_detector.py, feature_extractor.py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]
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2026-05-09 firmware v3.5.1 + addon fixes: leak timer, K-factor, WebSocket, N+1 query
    Firmware (3.5.0 → 3.5.1):
    - Fix misleading "10s threshold" comments — fast valve seal check actually
    uses a 20s threshold in both globals and the lambda comment
    - Centralize flow meter K-factor (396.0) as a substitution so a hardware
    change only needs updating in one place; applied to all 4 lambda sites
    - Replace 0.5s accumulation in leak test elapsed timer with millis()-based
    wall-clock computation (elapsed = (millis() - start_ms) / 1000.0f) to
    eliminate scheduling-jitter drift over 30–60 minute tests; adds
    leak_test_start_ms_main and leak_test_start_ms_irr globals
    Addon:
    - Bump MIN_FIRMWARE_VERSION t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
    [database.py, device_discovery.py, esp-water-shut-off-3_5.yaml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]
2026-05-09 addon cleanup: fix orphaned fixture_id, consolidate upserts, persistent ws_request, IngressTemplates to module level
    database.py:
    - delete_cluster now NULLs both cluster_id and fixture_id on affected events
    so deleted clusters leave no dangling fixture references on their events
    - Consolidate upsert_training_state, upsert_sensitivity_config,
    upsert_learning_config, and upsert_leak_test_schedule into a shared
    _upsert_by_circuit helper (~52 lines → 4 one-liners + shared impl);
    all public signatures unchanged
    ha_client.py:
    - ws_request now reuses a persistent WebSocket connection (_ws_oneshot)
    instead of opening a new connection + auth handshake for every call;
    reconnects lazily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
    [database.py, ha_client.py, main.py]
2026-05-09 Update device_discovery.py
    Four things cleared together when a new device is selected:
    fixture_clusters — deleted (old clusters don't apply to new setup)
    fixtures — deleted (old fixture definitions are invalid)
    events.cluster_id / fixture_id — NULLed (rows kept, associations reset so re-clustering can reclassify them)
    training_state.state — reset to 'idle' so the new device starts the training flow fresh
    [device_discovery.py]
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2026-05-10 fix(addon): 18-issue code review fixes — bugs, wrong results, quality
    Addresses all issues identified in a full addon code review. No firmware
    changes. Fixes are ordered by severity: crash bugs first, wrong-result
    bugs second, quality/future-proofing last.
    Bug fixes (crash / data corruption)
    -------------------------------------
    - device_discovery: fix FK violation on re-setup — delete
    fixture_ha_entity_map and fixture_daily_summary before DELETE FROM
    fixtures (child tables lack ON DELETE CASCADE)
    - backup: make import_history_archive fully transactional — a failure
    mid-import now rolls back all tables instead of leaving a partial merge;
    row counts now use before/after COUNT(*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
    [database.py, device_discovery.py, esp-water-shut-off-3_5.yaml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]
2026-05-10 fix(addon): second-pass review — correctness, safety, and robustness fixes
    Fixes 9 issues identified in a second-pass code review of the addon Python
    codebase. All 51 tests pass.
    Correctness
    -----------
    - database.py: volume baseline keys now use UTC (datetime.now(timezone.utc))
    instead of local time, fixing daily/weekly totals on non-UTC HA installs
    where the local midnight differs from SQLite's 'now'.
    Safety / crash prevention
    -------------------------
    - device_discovery.py: guard name_by_user None in exact-match search
    (partial-match path already had a guard; exact-match did not).
    - device_discovery.py: wrap save_discovery in `with db:` so a mid-write
    failure rolls back instea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
    [database.py, main.py, orchestrator.py]
2026-05-10 feat(dashboard): change "this week" volume to rolling 7-day window
    Replaces the calendar-week (Monday-reset) volume total on the dashboard with
    a rolling 7-day window, and fixes a timezone key mismatch introduced in the
    previous commit.
    Behaviour change
    ----------------
    The "This week" label and its underlying calculations now represent the past
    7 days (rolling) rather than the period since last Monday. This makes the
    figure stable day-over-day and avoids the sharp Monday drop to zero.
    Code changes
    ------------
    database.py — get_weekly_volume (hourly_volume path):
    SQL cutoff changes from last-Monday midnight to datetime('now', '-7 days').
    database.py — compute_ha_weekly_volume (HA c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
    [database.py, orchestrator.py]
2026-05-16 Fix build failure, orchestrator resilience, and firmware safety bugs
    Fixes five high-priority bugs identified in code review.
    Dockerfile (A1)
    - Remove COPY firmware line — firmware/ does not exist inside the
    addon build context, causing Docker build to fail with COPY failed.
    Firmware is flashed to ESP32 via ESPHome and is not needed at runtime.
    Orchestrator (A3)
    - Add _supervise() wrapper around all seven background tasks in
    asyncio.gather(). Previously, an unhandled exception in any one task
    (ha_event_loop, feature_extractor, training_manager, etc.) would
    propagate through gather() and kill the entire orchestrator, silently
    halting all monitoring. Each task now restarts inde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
    [esp-water-shut-off-3_5.yaml, leak_test_scheduler.py, orchestrator.py]
2026-05-16 Defensive fixes — entity guards, abort safety, SQLite, wiring fault detection
    Four medium-priority fixes from code review.
    EventDetector (A4)
    - Guard flow_sensor, pressure_fast_sensor, and flow_onset_sensor
    subscriptions with if checks before calling subscribe_entity(), matching
    the pattern already used for valve_entity. Subscribing to an empty string
    when an entity role is unmatched produces wasted callbacks and masks
    discovery errors.
    Leak test abort route (A5)
    - Remove the unconditional open_valve call in the leaktest_abort handler.
    The firmware's leak_test_restore script already handles the valve reopen
    with a fault guard (!fault_main). Sending an additional open command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
    [database.py, esp-water-shut-off-3_5.yaml, event_detector.py]
2026-05-16 Polish — pulse counter debounce, discovery regex robustness, version warning
    Three low-priority fixes from code review.
    Firmware — pulse counter debounce (F4)
    - Add internal_filter: 13us to both pulse_counter sensors (GPIO39 main,
    GPIO38 irrigation). pulldown mode prevents floating inputs but does not
    debounce RF noise from nearby valve motor inductance or long cable runs.
    Without a filter, noise can produce false pulse counts at rest, creating
    phantom flow events in the addon. 13us is the ESPHome lower limit and
    appropriate for hall-effect / mechanical flow sensors at these flow rates.
    Device discovery — order-insensitive regex (A9)
    - Replace order-dependent patterns like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
    [device_discovery.py, esp-water-shut-off-3_5.yaml]
2026-05-16 refactor: replace hardcoded circuit roles with generic IDs + configurable display names
    Separates internal circuit identity from user-facing labels. Previously
    "main" and "irrigation" were hardcoded as both internal keys and display
    strings, breaking semantically for any install where the second valve isn't
    irrigation (duplex units, guest house, two mains, etc.).
    Internal IDs are now stable circuit_1 / circuit_2. Display names are
    configurable, defaulting to "Main" / "Irrigation", stored in a new
    circuit_labels table. The UI always shows display names; all routes, DB
    queries, and business logic use circuit IDs.
    Legacy URLs (POST /device/valve/main/open) continue to work via a static
    alias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
    [cluster_engine.py, config.py, database.py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]
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2026-05-16 feat: add reset button, alert switch, and threshold roles to discovery device_discovery.py — ROLE_PATTERNS additions for both circuits::
    - Reset buttons: fault_reset_button, trickle_reset_button
    (pattern: "Reset Safety Fault - Main / Irrigation")
    - Alert switches: alert_high_flow_switch, alert_pressure_drop_switch,
    alert_trickle_switch, alert_leak_test_switch
    (pattern: "Enable High Flow Alert - Main / Irrigation"; circuit_2
    includes |enable_high_flow_irr\b entity_id suffix fallback)
    - Threshold numbers: burst_threshold, pressure_drop_threshold,
    leak_pressure_threshold, trickle_min_flow, trickle_max_flow,
    trickle_duration, leak_test_duration_number
    (patterns match confirmed fi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
    [device_discovery.py]
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
